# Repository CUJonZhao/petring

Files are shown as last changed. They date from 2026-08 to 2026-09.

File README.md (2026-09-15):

# Delta Rest & Activity Prototype

This repository contains the working files for Delta's rest/activity prototype,
including hardware, enclosure CAD, ESP32 firmware and experiment reports.

The current Stage 1B goal is to record IMU activity offline, review complete
sessions in a phone browser, and sync them automatically to a private website
after the board returns to home Wi-Fi. A harness-mounted walking monitor is being explored
because of the assembled enclosure's size; wearing/dog tests are deferred.

**Latest (2026-09-15):** The first Delta-worn outing reached the private website:
two adjacent sessions contain 7,604 valid samples across 6 min 26 s. The second
file passed the site's integrity check, though its unconfirmed end coincided with
a low 3.13 V reading. The site now uses conservative activity labels rather than
claiming dog walk/run recognition. See [today's report](docs/2026-09-15_daily_report.md).

**Resume here (2026-09-15):** [Today's report / 今日报告](docs/2026-09-15_daily_report.md) ·
[long battery recording](experiments/battery_recorded_long_2026-09-13.md) ·
[Home Wi-Fi auto sync / 回家自动同步](docs/2026-09-11_home_wifi_cloud_sync.md).
The board records by itself away from home Wi-Fi, closes the session after it reconnects,
uploads it to the private site, and keeps the newest segments when storage is full:
it deletes cloud-confirmed history first, then only the oldest local-only segment
if that is needed for recording to continue.
**Validated on the board (2026-09-11):** the loop now runs unattended. A session
started from movement alone while still on home Wi-Fi, ended itself after five minutes
of stillness, uploaded, and appeared on the private site: 6,724 samples at 19.53 Hz.
Rest/walk is calibrated from a labelled indoor recording (149/149 windows agreed); the
run boundary is not. Open: a short real walk and wearing it on Delta's harness.

Previous (2026-09-09): [Today's report, photos and next steps / 今日报告](docs/2026-09-09_daily_report.md).
[Firmware handoff / 软件交接](docs/2026-09-09_offline_motion_logging.md).
The user has reported v0.4 printing and assembly complete. The offline recorder
has now been backed up/upgraded and tested on the board: a two-minute USB run
saved 2,279 samples through a Wi-Fi-off interval; CSV/binary comparison and
restart persistence passed. See the [physical report](experiments/offline_usb_bench_2026-09-09.md).
Average sampling was 18.97 Hz with flash-write timing gaps. The one-hour
battery supply and recorded-battery tests have passed; wearing/dog testing
remains pending.
Earlier mechanical details: [Stage 1B handoff](docs/2026-09-09_stage1b_handoff.md).

- [Current print package](hardware/enclosure/print_packages/delta_collar_v0_4_fit_print_20260909.zip)
- [Base/lid instructions](hardware/enclosure/v0_4/README.md)
- [Placement and cable-routing image](hardware/enclosure/v0_4/placement_routing.png)
- [Assembled prototype photo](hardware/reference_images/stage1b_v0_4_assembled_2026-09-09.jpg)

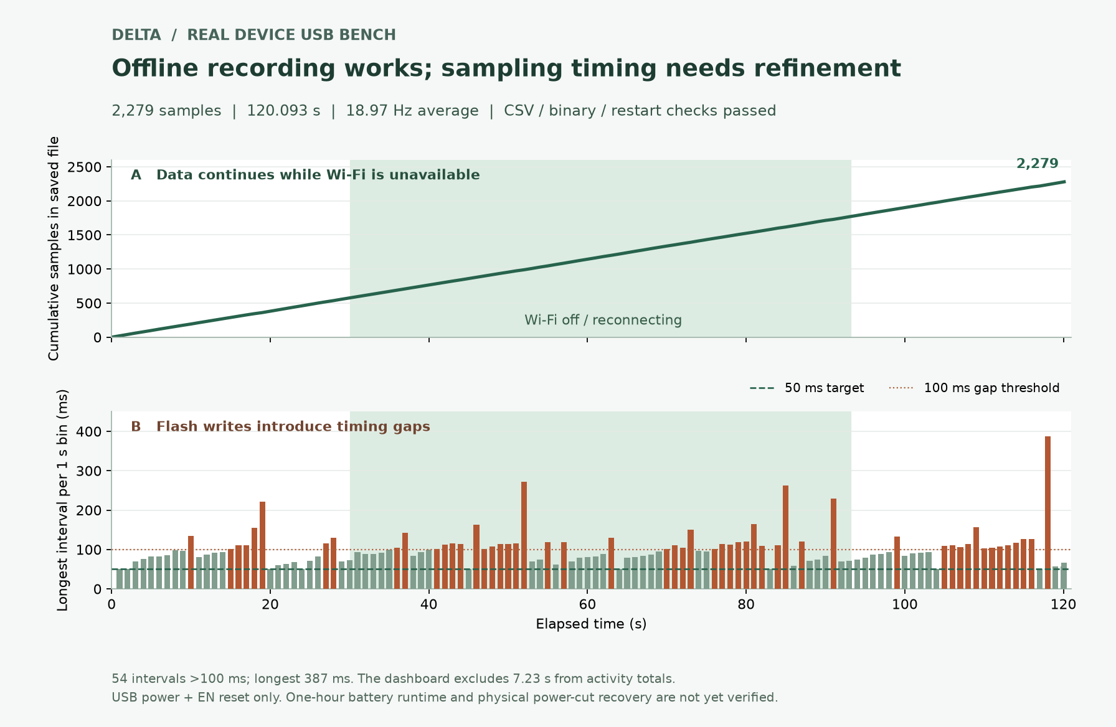
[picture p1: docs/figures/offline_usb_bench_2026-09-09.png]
Real USB bench: offline recording and sampling intervals


## Current Stage

Current status: Stage 1B home Wi-Fi auto-sync is implemented and passed a physical
bench end to end (record away, auto-close at home, upload, site confirmation).
The one-hour battery supply and recorded-battery validations have passed. A
real walk remains pending.

Stage 1A hardware bring-up is complete. The ESP32 Feather/HUZZAH32 V2,
LSM6DSOX IMU, LiPo battery path, Wi-Fi dashboard, enclosed USB bench test,
enclosed battery-only bench test, and four-minute hand-motion calibration have
all passed. The first dog-worn test is intentionally deferred because the
current enclosure is larger than desired for Delta.

Stage 1B focuses on:

- Reviewing the long battery recording's sampling gaps and capacity limit.
- Full-resolution data capture and automatic summary plots.
- Activity/rest threshold review from repeatable bench and hand-motion tests.
- Documenting the completed v0.4 enclosure and its remaining fit/retention details.
- Exploring a harness mount after the user resumes wearing tests.

As of 2026-09-06, a 3D printer has arrived and enclosure CAD work has
started. See
`docs/2026-09-06_stage1b_printer_arrival_and_enclosure_kickoff.md` and the
starting model in `hardware/enclosure/delta_collar_enclosure_v1.scad`.

As of 2026-09-08, the calipers have arrived and GitHub changes through
`7b54d0d` have been synced locally. Measured dimensions now feed a v0.3 low-wall
tray for powerless fit checks; see `hardware/enclosure/README.md`.
The first Feather, detached IMU, battery, and mounting-hole measurements are
recorded in `docs/2026-09-08_stage1b_caliper_measurements.md`. Hole-edge references
and the USB-inclusive length are confirmed, and mounting coordinates are derived.
Switch dimensions are recorded; the current preference is to mount it externally,
reserving cable exits and strain relief rather than internal switch space.
Underside and IMU slide-fit photos are archived. The user clarified that
19.59 mm measures the metal-pin gap, excluding the inward-projecting plastic
header bodies; the earlier usable-width estimate is withdrawn. The IMU can be
slid in from the side. The user confirms firm mechanical retention with no glue
or insulating layer, and an unchanged assembled height of 16.36 mm. Electrical
isolation and retention under motion remain to be verified; right-hand mounting
access was subsequently confirmed by the user on September 9.
A two-minute USB serial observation of this assembly then captured 2,370 samples
at 19.98 Hz with no firmware errors or post-startup resets. IMU temperature ranged
from 29.08 to 31.45 C. The user confirmed the battery was disconnected and reported
no physical anomalies during capture. See
`experiments/usb_slide_fit_2min_2026-09-08.md`; this is a short functional check,
not completion of enclosure, insulation, or wearability validation.

As of 2026-09-09, the user has printed the v0.3 tray and confirmed that the
board assembly and battery fit side by side with spare space. A removable
two-post cable guide (20 x 27 x 9 mm, shortened after the user's space check)
was designed for the long leads; see
`docs/2026-09-09_stage1b_tray_fit_and_cable_routing.md`. A v0.4 base and separate
lid now include four support posts, USB access, and a lay-in switch-wire exit.
The actual plug housing is 8.95 x 3.30 mm; the combined wire envelope is
3.32 x 1.59 mm, and the user confirms the IMU leaves the right holes accessible.
The battery plug's hard plastic projects 1.06 mm beyond the PCB edge, leaving
about 0.94 mm of nominal wall clearance; its raised wire bend needs a lid fit check.
See `hardware/enclosure/v0_4/README.md` for both STLs and fit instructions.
Mesh and nominal collision checks pass. The user subsequently confirmed printing
and assembly complete, with a [closed-case photo](hardware/reference_images/stage1b_v0_4_assembled_2026-09-09.jpg).
The final screw specification and internal retention details were not separately
confirmed; assembly completion does not certify wearing fit or waterproofing.

Stage 1 intentionally does not include medical diagnosis, production waterproofing, phone app deployment, GPS/LTE, or validated heart/respiration measurement.

## Next Work

Recommended next steps:

1. Take one supervised short real walk end to end: begin on battery, leave home
   Wi-Fi, return, and confirm automatic close and upload on the private site.
2. Review/download the real short recording in the phone-friendly `/records` page.
3. If fixed-rate behavior analysis is required, decouple sampling from synchronous
   flash writes and recheck interval distribution.
4. Use real recordings to refine activity reports. Do not advance wearing/dog
   testing until the user resumes that work.

## Repository Layout

- `docs/` - proposals, purchase/build notes, and PDF generation script.
- `firmware/` - ESP32 firmware (`imu_raw_stream` is the current recorder with home Wi-Fi sync).
- `hardware/` - wiring notes, enclosure sketches, hardware photos/diagrams, and enclosure CAD (OpenSCAD) starting point in `hardware/enclosure/`.
- `experiments/` - experiment plans and observation logs.
- `data/raw/` - raw CSV/log captures, ignored by Git except `.gitkeep`.
- `data/processed/` - processed analysis outputs, ignored by Git except `.gitkeep`.

## Key Documents

- `docs/canine_resting_vitals_smart_collar_proposal_v3_delta_first.md`
- `docs/canine_resting_vitals_smart_collar_proposal_v3_delta_first.pdf`
- `docs/stage1_purchase_and_build_notes.md`
- `docs/2026-08-12_stage1_handoff.md`
- `docs/2026-08-14_stage1_enclosure_bench_and_calibration.md`
- `docs/2026-09-06_stage1b_printer_arrival_and_enclosure_kickoff.md`
- `docs/2026-09-08_stage1b_caliper_measurements.md`
- `docs/2026-09-09_stage1b_tray_fit_and_cable_routing.md`
- `docs/2026-09-09_stage1b_handoff.md`
- [2026-09-11 daily report](docs/2026-09-11_daily_report.md)
- [2026-09-13 daily report](docs/2026-09-13_daily_report.md)
- [Home Wi-Fi auto sync](docs/2026-09-11_home_wifi_cloud_sync.md)
- [2026-09-09 daily report](docs/2026-09-09_daily_report.md)
- [Offline recording handoff](docs/2026-09-09_offline_motion_logging.md)
- [Physical offline USB bench](experiments/offline_usb_bench_2026-09-09.md)
- `experiments/usb_slide_fit_2min_2026-09-08.md`
- `hardware/enclosure/README.md`

## Safety Note

This is an engineering prototype, not a veterinary diagnostic device. During early tests, Delta should be supervised, the battery should not be compressed or exposed, and charging should not be left unattended.

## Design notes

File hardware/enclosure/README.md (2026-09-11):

# 小外壳：v0.4 底盒和盖子，沿用 v0.3 理线座

项目续接入口：[9 月 9 日日终报告](../../docs/2026-09-09_daily_report.md)。用户已确认 v0.4 打印和组装完成；当前优先离线记录，暂缓佩戴测试。

2026-09-09 最新：已根据补测完成 [v0.4 带盖试装版](v0_4/README.md)，包含 USB 开口、外置开关线槽与四根 Feather 支撑柱。

- [底盒 STL](v0_4/delta_collar_v0_4_base.stl)：65.25 × 65.25 × 21.36 mm，四柱已经合并在底盒内。
- [盖子 STL](v0_4/delta_collar_v0_4_lid.stl)：69.05 × 69.05 × 15.57 mm，包含向内伸出的线槽挡片，文件已摆成打印朝向。
- 两份都要导入；装配后名义总高 22.96 mm。网格、尺寸及名义碰撞检查通过；用户已完成打印和组装。
- 用户确认 IMU 不遮挡右侧孔；插头金属外壳为 8.95 × 3.30 mm，开关线合计外包络 3.32 × 1.59 mm。
- 柱子带 M2 试配导孔，实际锁固仍需螺钉。盖子松紧与全部线材走向需断电试装。

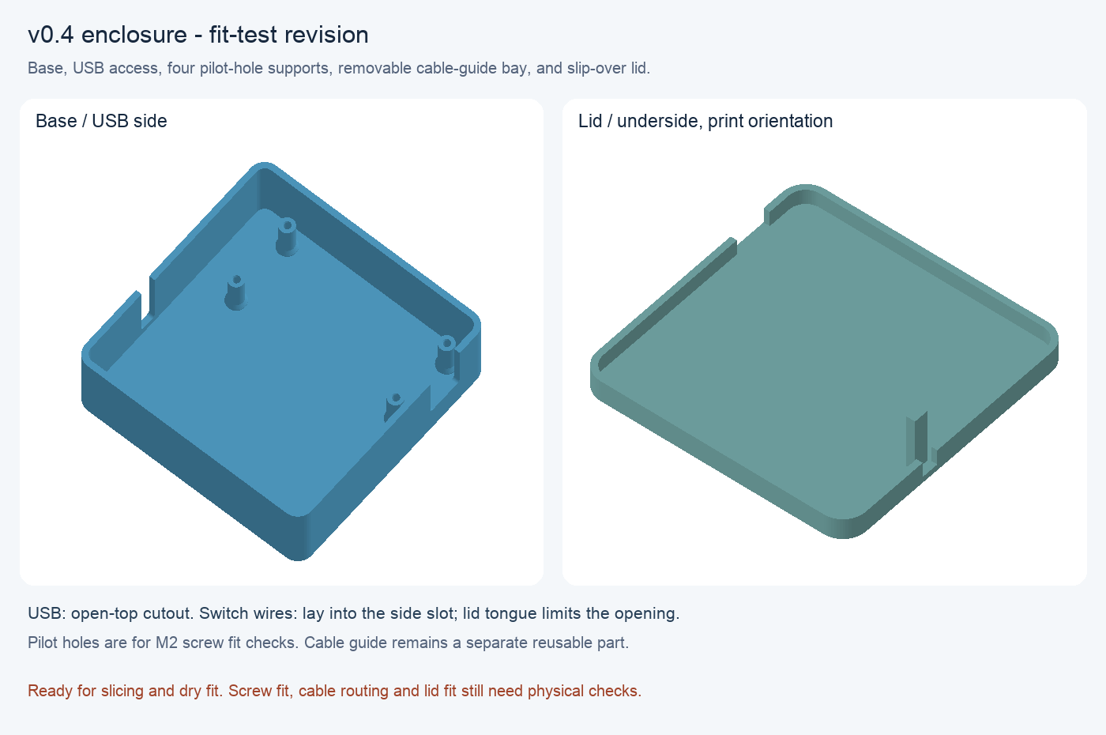
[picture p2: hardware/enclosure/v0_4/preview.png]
底盒及独立盖子


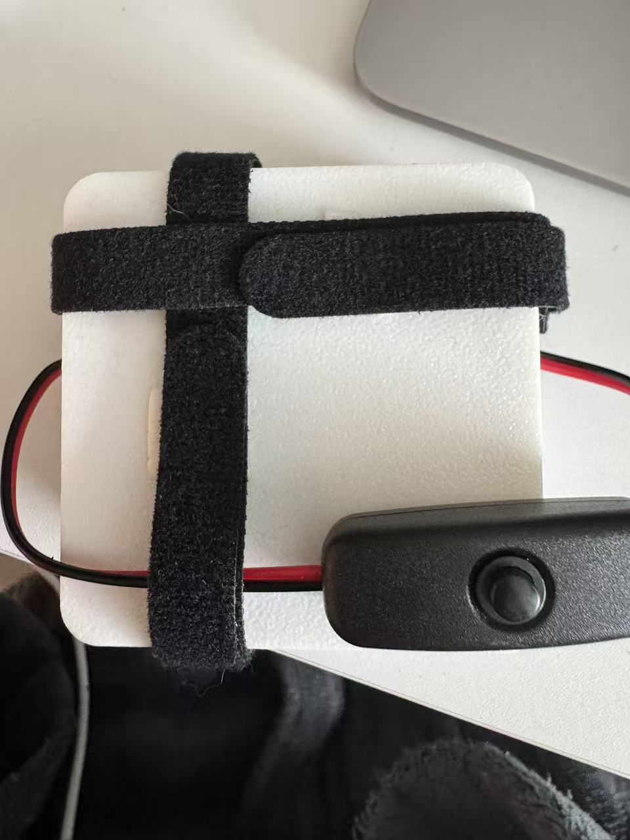
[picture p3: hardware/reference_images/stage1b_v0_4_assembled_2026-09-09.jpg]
已组装的 v0.4，交叉魔术贴和外置开关


照片记录整体外观；实际螺钉规格、内部固定和佩戴保持力仍没有单独验证。

## 正在试用的 27 mm 理线座

2026-09-09：用户已打印托盘并确认组件和电池可以并排放下，仍有空余空间；新增需求是整理较长的线材。

当前追加文件：[delta_collar_v0_3_cable_guide_27mm.stl](delta_collar_v0_3_cable_guide_27mm.stl)，尺寸 **20 × 27 × 9 mm**。
用户实测可用长边约 30 mm，已按要求缩至 27 mm；原 32 mm 版本仅作历史记录。
这是独立双柱理线座，可先放入电池旁空位试绕线，再用已有双面胶固定在托盘底面。
完整操作和摆放图见 [9 月 9 日理线记录](../../docs/2026-09-09_stage1b_tray_fit_and_cable_routing.md)。

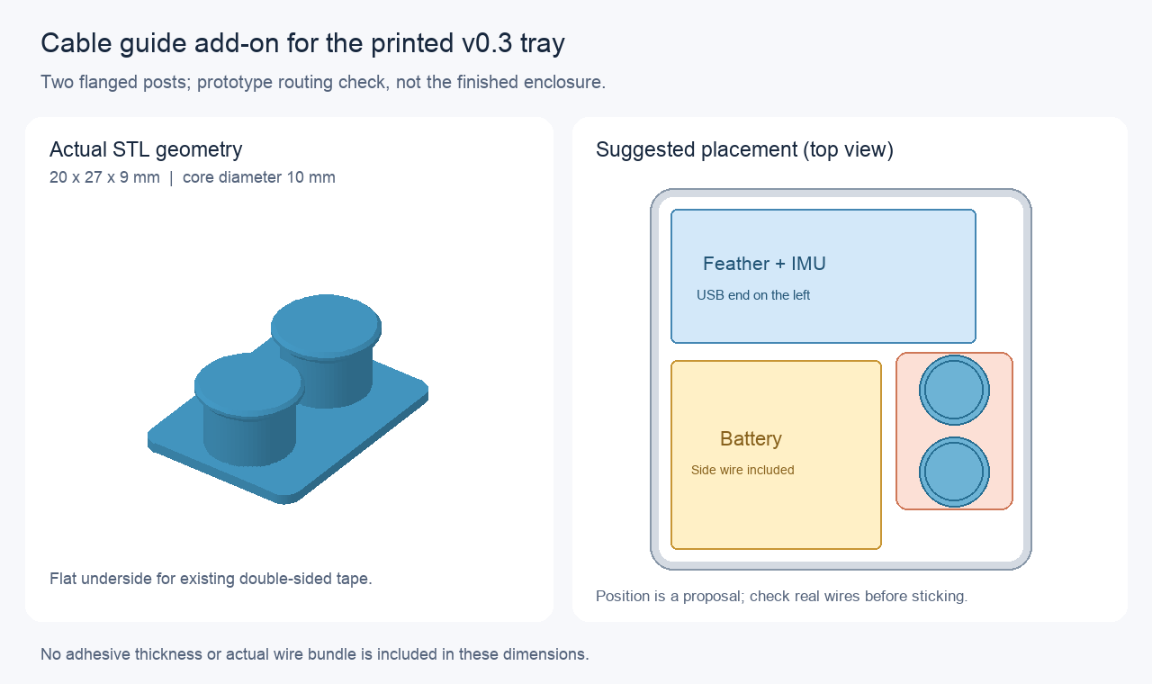
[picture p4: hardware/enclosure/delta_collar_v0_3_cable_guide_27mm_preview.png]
双柱理线座及建议位置


理线座已检查导出网格和尺寸。用户已确认整体组装完成，但合盖照片没有单独展示内部理线座及其固定效果。其 SCAD 可编辑；生成脚本依赖的库版本记录在对应 validation.json 中。
v0.4 给此配件预留位置，继续用独立理线座，便于复用和调整。

## v0.3 托盘参考

已打印的托盘文件：[delta_collar_enclosure_v0_3_fit_tray.stl](delta_collar_enclosure_v0_3_fit_tray.stl)。
此托盘用于断电检查占地和走线。它只有低侧壁，组件会高于侧壁；不是最终带盖外壳。

## 本版尺寸

| 项目 | 尺寸／状态 |
|---|---|
| 外尺寸 | 65.25 × 65.25 × 11.60 mm |
| 内部平面尺寸 | 62.05 × 62.05 mm（圆角附近空间略减） |
| 内部侧壁高度 | 10.00 mm |
| 底厚／壁厚 | 1.60／1.60 mm |
| Feather＋IMU 高度基准 | 16.36 mm；IMU 嵌在排针间，不重复加高 |
| Feather 含 USB 的参考占地 | 52.05 × 22.80 mm；外接线材另留空间 |
| 电池参考占地 | 35.90 × 32.25 mm，包含沿边电线 |
| 两组件摆放间距 | 3.00 mm，设计初值 |
| 周边留量 | 2.00 mm，设计初值 |
| 板长方向一端线材预留 | 8.00 mm，设计初值，不是已测弯曲半径 |
| 开关 | 外置 |

本版不设置固定柱，便于检查当前 IMU 位置是否挡住 Feather 右侧孔区。
四孔坐标已记录，但柱体直径和支撑通道尚未确定。低侧壁也让未确定出口位置的电线能够从上方绕出。

## 托盘原始试装步骤（并排占地已确认）

1. 拔掉 USB，保持电池与电路断开，保留当前卡住的 Feather＋IMU 组合，不为试装强拆。
2. 在 Bambu Studio 新建项目，导入上面的 STL。单位按 mm、缩放保持 100%，核对外尺寸为 65.25 × 65.25 × 11.60 mm。平底朝打印板、开口朝上，沿用已验证的打印机／材料配置。托盘几何不需要支撑；先切片检查有完整底面和开放顶部，再自行开始打印。
3. 冷却并清理毛刺后，轻放组件。Feather 的长边与托盘一边平行，电池放在它旁边，电池 35.90 mm 长边与 Feather 长边同向。开关留在盒外；不要叠压电池或用力把组件压向底面。
4. 检查：电池能平放取出；两组件和线材互不挤压；接头能插拔；四个 Feather 孔周围是否有放支撑柱的空间。元件高出低侧壁是预期效果，现阶段不尝试合盖或通电。
5. 把组合、电池和线材摆好，提供一张俯视照片和一张侧面照片，并指出碰到侧壁或走线太紧的位置。下一版据此确定柱位、完整盒高、出线口和盖子。

若目前已有打印好的旧托盘，可以先做同样的断电摆放，反馈卡住的位置；旧模型的电池宽度为 29 mm，与实测 32.25 mm 不符，不能据其尺寸认定新布局能放下。

## 文件与核对

- [SCAD 模型](delta_collar_enclosure_v0_3_fit_tray.scad)：含预览用组件包络，包络不导出到 STL。
- [生成脚本](generate_v0_3_fit_tray.py)：仅依赖 Python 标准库，修改脚本中的实测尺寸／设计留量并运行，可同步再生成 SCAD 和 STL。
- [网格检查结果](delta_collar_enclosure_v0_3_fit_tray_validation.json)：读取导出的二进制 STL 检查了外尺寸、544 个三角面、单个连通实体、每边恰好两个相邻面、朝向及体积。实体表面闭合，托盘顶部仍是开口；两者不是同一概念。

托盘导出时未运行 OpenSCAD 渲染或 Bambu 切片检查，也未由助手发起打印；用户后续已完成打印及并排摆放。导出使用与 SCAD 一致的轮廓直接生成网格。
旧 `delta_collar_enclosure_v1.scad` 及 v0.1／v1／v1_1 STL 保留为历史起点；当前带盖试装使用 v0.4 底盒和盖子，理线座使用带 `27mm` 后缀的 v0.3 文件。

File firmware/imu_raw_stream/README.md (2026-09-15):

# IMU stream and offline activity recorder

**2026-09-11 — home Wi-Fi sync.** Once site credentials are provisioned over USB
(`experiments/cloud_sync_mac.sh validate`), recording is automatic: a session starts
~10 s after the saved home Wi-Fi is out of reach (30 s grace after power-on), ends 15 s
after a stable home reconnect, and every unconfirmed session is uploaded newest-first
in resumable 16 KiB chunks with SHA-256 confirmation. When space is needed,
cloud-confirmed sessions are deleted oldest-first. If Delta remains away long enough
that this is not sufficient, it closes the current file, starts a new segment, and
evicts the oldest local-only segment only as needed to keep the newest data recording.
`GET /api/cloud` and serial `Q` report sync state; `/records` shows it with per-session badges. Without
credentials the original record-from-power-on behavior below is unchanged. Details:
[docs/2026-09-11_home_wifi_cloud_sync.md](../../docs/2026-09-11_home_wifi_cloud_sync.md).

**2026-09-09:** offline logging and the phone-friendly `/records` page are now
uploaded to the board. The first USB bench passed actual Wi-Fi-off recording,
CSV/binary comparison and restart persistence: 2,279 samples over 120.093 seconds,
18.97 Hz average. Synchronous flash writes caused 54 intervals over 100 ms;
timestamps preserve these gaps. One-hour battery runtime, direct power-cut
recovery and on-device full-disk behavior remain untested. See the
[physical bench report](../../experiments/offline_usb_bench_2026-09-09.md).

This Stage 1 test firmware configures the LSM6DSOX for a 104 Hz accelerometer (+/-4 g) and gyroscope (+/-500 deg/s) sample rate. It sends a CSV row to USB serial every 50 ms and samples the Feather's battery-voltage divider once per second.

It also runs a password-protected Wi-Fi access point:

- Network: `Delta-Collar`
- Password: `deltacollar`
- Dashboard: `http://192.168.4.1`

Connect a phone or computer to the `Delta-Collar` network, then open the dashboard
address in a browser. The dashboard shows live sensor data, a simple Resting/Active
state, battery voltage, a short activity chart, and browser-side CSV export.
The live chart/export still covers only about 45 seconds; use **离线记录 / 完整历史**
(`/records`) for recordings saved on the device. Neither page needs internet.

## Offline recording workflow

1. Power on. If the IMU and storage initialize successfully, a **new recording
   starts automatically**, even without a phone, router or internet connection.
2. In `/records`, check that the saved sample count increases. Closing the page
   or leaving home Wi-Fi does not stop recording.
3. Reconnect directly to `Delta-Collar`, or visit the device's local IP on home
   Wi-Fi. Press **停止并保存** before switching power off or downloading data.
4. View an entire recording, download CSV, or download the original binary file.
   The CSV has every validated saved sample, not just the browser chart window.
   Confirm the download in the phone's Files/downloads before deleting anything.
5. Press **开始新记录** to record again without rebooting. This attaches the phone's
   current date/time to the new session. Automatic boot/serial starts have relative
   time only, explicitly shown as `未设置日历时间`; no offline clock is invented.

The recorder targets 20 samples/second and preserves raw accelerometer/gyroscope
counts, sensor temperature, battery voltage, a quantized activity score and the
heuristic state. Data is buffered for at most about one second during normal
operation and flushed using checked `fflush`/`fsync`; a normal stop flushes the
remaining partial batch. Each record has a CRC. Unexpected power loss can lose
the pending batch/in-flight write; the actual power-loss behavior needs a board
test. This is not a hard real-time or lossless acquisition guarantee: flash and
network servicing may add timing gaps. The recorded timestamps preserve them.

An unclosed `.open` file is retained as **interrupted** after reboot; a new file
is created without resuming or overwriting it. Normal stops use `.bin`; full disk,
write errors and repeated IMU failures use `.full`, `.error`, `.sensor`.
Twenty consecutive IMU read failures stop recording. With home sync configured,
storage acts as a latest-record ring: cloud-confirmed history is discarded first;
if that cannot make room during a long away recording, the oldest local-only
segment is discarded and the newest segment continues. This means an exceptionally
long trip with no return to home Wi-Fi can lose its oldest not-yet-uploaded segments.
The current segment is never deleted while it is being written. Without home sync
credentials, full storage still stops capture and is reported in the UI.

Large transfers, directory listings and deletions are rejected with HTTP 409
while recording, so a CSV download cannot pause an active session. Small status
and live dashboard requests remain available. Wi-Fi remains enabled for access
and reconnection by default. Serial `O` temporarily disables Wi-Fi without stopping
the recording; `W` restores Wi-Fi and the saved network; `N` prints network status.
These controls allow a bench test with the radio actually disabled. They do not
erase credentials and are not persistent across reboot. Home Wi-Fi cloud upload is
described at the top of this file; Bluetooth sync and a phone-page radio control
are not implemented.

## Storage and migration

`partitions.csv` preserves the offsets and sizes of **all existing partitions**,
including NVS/Wi-Fi credentials and the old `spiffs` battery-log partition. The
formerly unused upper 4 MiB at `0x400000` becomes a separate `motion` LittleFS
filesystem. This partition layout is for the **8 MB Feather ESP32 V2 only**.
The build pins Espressif32 7.0.1 / Arduino 2.0.17, whose LittleFS configuration
supports three partitions; this firmware mounts two.

- New record payload: 24 bytes/sample, 32-byte session header.
- One hour at 20 Hz: **1,728,032 bytes** (~1.73 MB / 1.65 MiB), before filesystem overhead.
- A 128 KiB reserve is maintained; displayed remaining time also allows 15% for
  overhead. It estimates storage capacity, **not battery life**.
- The observed practical ceiling is about **150,000 samples / 130 minutes** in
  one continuous segment (the 2026-09-12/13 battery recording). With ring
  retention enabled, longer away periods are split into segments and retain the
  newest ones instead of stopping at that boundary.
- Existing battery logs remain in their original partition.
- Mounting never uses destructive format-on-failure. A partition is initialized
  only after a full scan proves that every byte is erased (`0xff`). An unreadable
  nonempty partition is left intact, reported unavailable, and requires recovery.
- Use a normal firmware upload, which includes the new partition table. **Do not
  use `erase_flash` or `uploadfs` for this upgrade.** Back up the board's existing
  data before an upgrade. The first physical upgrade has been backed up and
  performed; all 560 pre-existing battery rows were preserved.

## Saved format and recovery

All numbers use explicit little endian encoding in `src/motion_format.h`.
Header: `DLOG`, uint16 version 1, uint16 record size 24, uint32 period 50 ms,
uint32 start uptime, uint64 optional start Unix milliseconds (0 = unknown), six
reserved bytes, CRC-16/CCITT-FALSE over the first 30 bytes.

Record: uint32 elapsed ms; three int16 acceleration counts; three int16 gyro
counts; int16 temperature count; uint16 battery mV; uint8 rounded activity score
times 255; uint8 flags (bit 0 Active); CRC-16/CCITT-FALSE over the first 22 bytes.
CRC parameters: polynomial 0x1021, init 0xffff, no reflection/final xor.
Acceleration scale is 0.000122 g/LSB, gyro 0.0175 deg/s/LSB, temperature
`25 + count/256` C. It is IMU chip temperature, not animal body temperature.

The device validates all full records before CSV export. The page also compares
the received CSV row count with `X-Delta-Records` before reporting success, and a
read failure during streaming aborts the transfer. An incomplete final
record is omitted (and its byte count shown); corrupt full records cause HTTP
422 instead of silently exporting bad measurements. Download the original binary
for independent inspection/recovery:

```sh
python3 experiments/decode_motion_log.py data/raw/delta-ID.bin data/processed/delta-ID.csv
# Only if corruption was reported: explicitly recover the intact prefix.
python3 experiments/decode_motion_log.py data/raw/delta-ID.bin data/processed/delta-ID.csv --recover-prefix
```

Run those commands from the repository root. The decoder reports record count,
last timestamp, optional start time and any recovery warnings as JSON. It writes
the CSV atomically, preserving an existing output if validation fails. CRC damage
ends recovery at the first bad record; it does not guess missing values.

Saved CSV columns:

`elapsed_ms,ax_g,ay_g,az_g,gx_dps,gy_dps,gz_dps,temp_c,motion_g,activity_score,battery_v,state`

The history page reads the full CSV and plots time-binned averages. Activity/low
activity durations use successive valid intervals <=100 ms; larger gaps and the
time before the first sample are marked uncovered. This is an exploratory
threshold summary, not a validated behavior classifier.

## Tests

```sh
# From the repository root; Python 3 + a C++11 compiler.
python3 firmware/imu_raw_stream/tests/test_offline_log.py
# With Playwright available to Node:
node firmware/imu_raw_stream/tests/records_page_test.cjs
# From this firmware directory:
pio run
```

The host test exercises the actual C++ buffer/codec with 72,000 synthetic samples,
an independent Python CSV decoder, bit corruption, every possible truncated tail,
timestamp regression, failed writes/partial buffers, and partition compatibility.
The browser test uses mocked device APIs, checks full-hour chart/download, state
controls, interrupted sessions, errors, disconnect/reconnect, deletion cancellation
and mobile overflow. These do not substitute for LittleFS/power-loss/battery tests
on the ESP32. Set `PLAYWRIGHT_CHROMIUM_EXECUTABLE` to use an installed Chrome and
`DELTA_UI_TEST_OUTPUT` to choose the screenshot/download output directory.

For an attached board with this firmware already uploaded, the physical USB
bench script records 120 seconds, temporarily disables the board's Wi-Fi for
about 60 seconds, downloads and compares CSV/binary data, and uses an EN reset to
check completed/interrupted records. It creates sessions but never deletes them:

```sh
python3 experiments/validate_offline_recorder.py --port /dev/cu.usbserial-59680111041 \
  --url http://DEVICE_IP --output data/raw/offline_bench_RUN
```

Run from the repository root with `requests` and `pyserial` installed. The script
restores Wi-Fi and stops recording on exit. An EN reset is not a physical power
cut and this USB-powered run does not measure battery endurance.

To also use the dashboard while the computer stays on home Wi-Fi, open `http://192.168.4.1/setup` while connected to `Delta-Collar`. Enter the home network name and password in that page. After the ESP32 connects, the page displays its new local IP address and stops the temporary access point to reduce normal operating power. If the home network becomes unavailable, `Delta-Collar` automatically returns for configuration or recovery.

The existing USB serial CSV columns remain:

`ms,ax_g,ay_g,az_g,gx_dps,gy_dps,gz_dps,temp_c,motion_g,battery_v`

With the board still on a desk, the acceleration magnitude (`motion_g`) should stay near `1.0`. During tilting or hand motion, the axis values and gyroscope values should change.

## Run

1. Keep the LSM6DSOX connected to the Feather STEMMA QT port.
2. From this directory, run `pio run --target upload`.
3. Open serial at 115200 baud and collect the CSV output.

`battery_v` is an approximate voltage from the onboard 1:2 voltage divider. It is useful for tracking charge and discharge, but it is not a calibrated battery gauge.

Every 30 seconds, the firmware also saves `ms,battery_v` to its original internal
flash partition. Serial commands: `S` stops/saves motion recording; `R` starts a
new recording; `L` prints recording status; `D` prints the old battery log (only
when motion recording is stopped); `C` clears only the battery log. None of these
commands delete motion sessions. Stop before unplugging USB to end a session cleanly.

The IMU configuration is not persistent: it resets when the board loses power.

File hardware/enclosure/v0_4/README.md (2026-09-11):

# v0.4：带 USB 开口、出线槽、四柱和独立盖子的试装版

2026-09-09。沿用已经通过实物并排试放的底盒平面尺寸，增加完整高度、Feather 支撑柱和盖子。
用户现已确认打印、组装完成，照片可见魔术贴保持盖子与外置开关；见 [今日报告](../../../docs/2026-09-09_daily_report.md)。
下文保留参数、打印与复装参考。具体螺钉规格、内部保持力及佩戴配合没有被这张合盖照片单独验证。

底盒与盖子，均为打印方向

## 打印文件

可直接下载 [v0.4 试装打印包](../print_packages/delta_collar_v0_4_fit_print_20260909.zip)：包含下列两份 STL、可选的 27 mm 理线座、摆放图和简明说明。打包时已核对 STL 尺寸与压缩包内文件哈希。

| 零件 | 文件 | 导入后尺寸 X × Y × Z（mm） | 朝向 |
|---|---|---|---|
| 底盒，含四根柱子 | [delta_collar_v0_4_base.stl](delta_collar_v0_4_base.stl) | 65.25 × 65.25 × 21.36 | 平底贴板、开口向上 |
| 盖子，含出线挡片 | [delta_collar_v0_4_lid.stl](delta_collar_v0_4_lid.stl) | 69.05 × 69.05 × 15.57 | 外侧大平面贴板，盖内侧及挡片向上；文件已翻好 |

两份都要导入，作为两个独立物体排列，缩放保持 100%。不要把盖子重新翻成盖住底盒的方向打印。
盖子主体只有 5.6 mm 高，STL 的 15.57 mm 高度包括向盒内伸出的出线挡片。装好后的总外尺寸为 **69.05 × 69.05 × 22.96 mm**。

沿用已验证的打印机、材料和参数。按给定方向，几何没有要求额外支撑的封闭悬空顶面；仍先检查切片预览，确认四根柱子、柱内导孔和盖上挡片完整。助手未启动打印。

## 本次收到的补测

- 实际 USB 线插头外壳：**8.95 × 3.30 mm**。用户澄清外壳为金属，原先关于“塑料头高度一致”的描述不作为另一个尺寸。
- 当前 IMU 不遮挡 Feather 右侧两个孔，用户确认下方可放支撑柱。
- 白色电池插头插好后，硬塑料超出 Feather PCB 长边 **1.06 mm**，不含软线。当前位置板边至内壁 2.00 mm，因此硬插头名义平面间隙约 **0.94 mm**；此数值不能作为软线弯曲空间。
- 开关线合并的自然外包络：**3.32 × 1.59 mm**，按本次询问的合计宽、厚记录。槽内需容纳的全部线应一起试放。
- 组合高度继续采用 **16.36 mm**，不再次叠加 IMU 厚度，也不要求拆出 IMU 加胶。

## 结构和装配

**Feather 四柱。** 柱顶距盒内底面 10.10 mm，对应 9.10 mm 下排针突出量加 1.00 mm 离底间隙。柱身直径 4.00 mm，底部加宽到 5.20 mm。四孔位置采用用户孔内缘测量所推导的坐标，仍需实物对孔。柱内为直径 1.60 mm、深 6.00 mm 的 M2 试配导孔，入口带扩口；柱子负责支撑，配合适的螺钉后才形成锁固。

现有采购记录没有确认 M2 螺钉。没有螺钉也能先轻放板组检查四孔和高度，不能把这一步当作板子已固定。螺钉长度取决于实际穿板厚度，伸入柱内应短于 6 mm；导孔是否适合所用螺钉还需试配，不是预制金属 M2 螺纹。

**USB 充电/数据开口。** 位于 Feather USB 一侧，净宽 **10.15 mm**，即插头宽度每侧加 0.60 mm。开口从距内底面 6.00 mm 处一直开到上缘，合盖后最高净空 13.36 mm；底角圆角处宽度略减。较大的垂直窗口用于容纳尚未直接测量的接口中心高度，实际插入时核对外壳及线根不碰盒壁。盖裙同步避让，合盖后可插拔 USB。接口沿板宽居中的位置参考 [Adafruit 官方 PCB 文件](https://github.com/adafruit/Adafruit-ESP32-Feather-V2-PCB)，板长、板宽与四孔位置继续以用户实测为准。

**外置开关出线口。** 位于理线座一侧的盒壁，槽宽 **4.52 mm**，底部圆角半径 1 mm。合盖后开口最大高度 **3.39 mm**，在圆角以上已核对 3.32 × 1.59 mm 的矩形线束可通过。开盖时直接把线放入 U 形槽，再盖上盖子，免去把既有插头穿过小孔。挡片厚 2.20 mm，进入槽内但不夹紧线束；它限位，不代替外部防拉扯固定。

**盖子。** 外套式盖裙，单侧设计间隙 0.30 mm、重叠高度 4.00 mm，顶厚 1.60 mm。当前是台架试装配合盖，没有锁扣；实际松紧取决于打印结果。使用现有魔术贴可作临时整盒保持，后续再结合外部开关及项圈固定一起验证。不要靠挤线来让盖子落到底。

**27 mm 理线座。** 继续使用 [20 × 27 × 9 mm 独立配件](../delta_collar_v0_3_cable_guide_27mm.stl)，本版留位，不重复打印或合并到盒底。相对底盒外角的建议左下/起始坐标仍为 X=42、Y=28 mm；电池起点为 X=3.6、Y=29.4 mm。坐标方向见下文装配预览：USB 在 X 最小的一侧，Feather 和电池沿 Y 并排。模型已检查理线座实体不碰挡片；粘胶厚度、绕线后的高度及余线回弹还需要实际试放。

## 复打／复装参考步骤

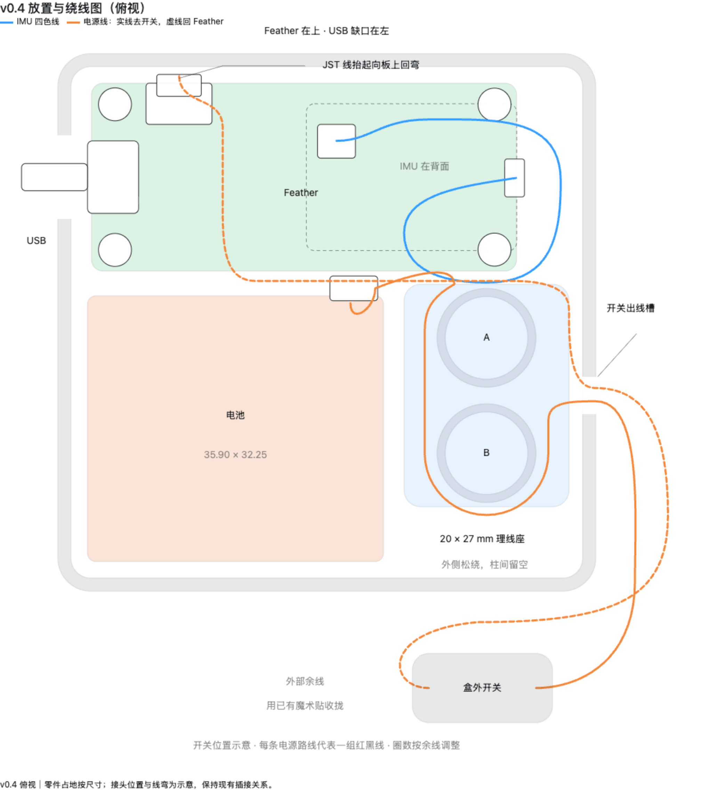
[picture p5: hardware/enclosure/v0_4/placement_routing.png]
建议俯视摆放与走线


可下载 [交互图 HTML](placement_routing.html) 后用浏览器打开，分别切换 IMU 线和开关电源线。[可编辑图源](placement_routing.fragment.html)已随仓库归档。图是本版参数的快照，修改 CAD 布局后应同步更新图中的尺寸与路线。

摆放图的零件占地来自本版参数；插接点、接头形状和软线走向为示意，不是按线长或最小弯曲半径完成的仿真。每条橙色路线代表一组红黑线：实线从电池经外侧绕柱到外置开关，虚线由开关回到 Feather；蓝色代表整条 IMU 四色线。保持现有插接关系，不改接线。

先只摆组件，再放 IMU 松弯，最后沿两柱外侧整理电源余线。IMU 线不强行绕完整一圈，也不穿过两柱挡边之间的窄缝。Feather 电池插头处的线向上抬起后回弯到板上方，不向 0.94 mm 的边缝塞线；这段和 IMU 松弯都需检查合盖高度。图中接头可在邻近可用空间微调，不能压在电池下或用盖子压住。

1. 等当前理线座完成，先试放和松绕线，记录是否有线圈超出底座占地。
2. 导入本版底盒和盖子，核对上表尺寸与朝向，再切片打印。
3. 断开 USB 和电池后，板组轻放到四柱上，检查每个孔都对准、板子平稳、排针不顶底；不要为对孔强拆 IMU。
4. 电池平放到旁边，理线座放入预留空位；把所有要通往开关的线一起放进槽内，开关保持外置。
5. USB 线电脑端断开时试插拔板端；再轻合盖，检查挡片没有夹线、盖沿能够落到底。反馈顶视图和侧视图及任何碰撞点，再调整间隙和完成固定。

用户已确认整体组装，后续也完成了 USB 离线记录短测。板组锁固、电池保持、外置开关及线材防拉扯的具体细节与佩戴保持力仍需单独记录；USB 短测不等同于完整机械或续航验证。

## 参数与检查

- [design_inputs.json](design_inputs.json)：实测值与设计留量分开记录。未知实测值为 null 时，正常导出会拒绝，`--draft` 仅输出带后缀的评审草稿。
- [generate_enclosure.py](generate_enclosure.py)：参数化实体生成、STL 重新读入验证和实际网格预览。Python 依赖见 [requirements.txt](../requirements.txt)，验证时使用 Python 3.12.3。绘图字体当前使用 macOS 系统 Arial，换系统时需修改字体路径。
- [assembly.scad](assembly.scad)：装配查看器，导入生成的 STL 和组件包络；`show_lid=true` 查看盖合位置。尺寸编辑入口是 JSON，不是这个查看器。
- [validation.json](validation.json)：底盒 4,028 面、盖子 602 面；各为单个闭合实体，朝向一致、无退化面、外尺寸正确。名义合盖状态无底盒/盖子体积干涉，USB 与线束通道探针通过，电池及理线座的名义包络无干涉。

生成命令：

```sh
python hardware/enclosure/v0_4/generate_enclosure.py
```

网格和名义包络检查不能替代实际打印公差、焊点/接插件占位、螺钉试配与最终线材布局检查。

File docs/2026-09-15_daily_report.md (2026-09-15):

# Delta 项目日报与续接指南 — 2026-09-15

今天完成了第一次 Delta 实际佩戴外出的数据核对，并把设备的满存策略改成
“优先保留最新记录”。网站的活动摘要也已改成更保守的观察标签，避免把尚未
用犬只真实数据标定的阈值误说成“走路／跑步识别”。

## 今天的结论

| 项目 | 状态 | 可复核结果 |
|---|---|---|
| 首次 Delta 佩戴外出 | **数据已收到** | 网站已有两段相邻记录：9 月 14 日 21:13:17（3 分 02 秒、3,586 条、正常结束）和 21:17:04（3 分 24 秒、4,018 条） |
| 第二段的文件完整性 | **通过** | 网站保存了完整原始文件；4,018 条有效样本，19.7 Hz，采样间隙 4.2 秒（跨度的 2.1%） |
| 第二段的结束原因 | 待结合现场确认 | 记录内电压 3.30 → 3.13 V，且没有写入正常结束标记；这与低电压／掉电相符，但不把它当作已由硬件完全证明的结论 |
| 充电复核 | 正在恢复 | 外置开关打开后，实测工作电压曾由约 3.87 V 上升至约 3.96 V；CHG 指示灯亮表示正在充电，不能单独证明已充满 |
| 私有网站 | 已更新并发布 | 活动呈现改为观察性“静止／活动／持续高活动”；低电压提示和相邻分段汇总已加入，站点仍仅所有者可见 |
| 本地固件的最新记录保留 | 代码和主机模拟通过 | 满存时先删除已被网站确认的最旧记录；仍不足才删除最旧的仅本地旧分段；当前写入的分段绝不删除 |
| 板子固件 | **已刷写并启动验证** | 以普通固件上传完成芯片端哈希校验；未执行 `erase_flash` 或 `uploadfs`，运动分区未被清空 |

## 外出数据：没有白费

两段记录合计 **6 分 26 秒、7,604 条样本**。两段之间约有 45 秒间隔，
因此不能视作严格连续的一条轨迹；但每一段实际到达网站的数据都有效。第一段
正常结束；第二段虽标为“结束待确认”，网站的完整性校验通过，表示原始文件
不是因传输而丢失或损坏。

第二段结束时的 3.13 V 已明显偏低，结合当时设备中途停止的现象，低电压是目前
最合理的解释。下一次外出前，应在外置开关**打开**的状态下继续充电至 CHG 熄灭
或电池工作电压稳定在约 4.1–4.2 V；充电仍须有人看护，若电池异常发热、鼓包或
有异味则停止使用。

## 容量与新的满存策略

`motion` 分区为 **4 MiB**；每个 IMU 样本为 24 字节，20 Hz 时理论上一小时
原始数据约为 1.73 MB。实际长记录已经测到单段 **150,289 条、130 分 38 秒**，
这比公式更可信地代表当前文件系统和采样间隔下的容量边界。

原来的行为是：已上传的记录可在空间紧张时清理，但如果设备长时间离开家中
Wi-Fi、所有旧记录都尚未上传，记录会最终因存储满而停止。现在的固件改为：

1. 空间需要时，先清理网站已以 SHA-256 确认收到的最旧文件；网站上的副本保留。
2. 若仍不足，当前段会先正常收尾，再新开一段；仅删除最旧的、尚未上传的
   本地旧段，给新段让出空间。
3. 正在写入的当前文件和刚结束、最新的那一段都受保护，长途记录会成为若干
   分段，设备尽可能保留最近的部分。

这是明确的数据取舍：**极长时间不回家同步时，最早的未上传分段可能会被淘汰，
以换取最新的记录继续保存。** 在能回家同步的正常流程中，优先删除的是已有
云端完整副本的历史记录。

实现位于 [cloud_sync.cpp](../firmware/imu_raw_stream/src/cloud_sync.cpp) 和
[cloud_sync.h](../firmware/imu_raw_stream/src/cloud_sync.h)；手动开始、自动离家开始
和家中活动开始均使用同一套空间策略。本地 `/records` 页会显示本次开机清理数，
并区分其中有多少是“仅本地旧段”。

## 网站分析的调整

私有网站已发布新的观察规则：

- 静止阈值：低于 **50 mg**；
- 高活动阈值：高于 **600 mg**；
- 只有连续 **6 秒**的高活动才显示“持续高活动”；短暂峰值只作为短时高活动候选；
- 不再把这些当前阈值直接命名为犬只“走路／跑步”。

这些是展示和后续校准的起点，不是医学指标，也不是已由 Delta 真实佩戴数据验证
的步态分类。下一次在充分充电后取得更长的佩戴样本，才能据此调整阈值。

## 验证和已知边界

- `sh firmware/imu_raw_stream/tests/cloud_sync_sim/run.sh`：通过。该主机模拟验证
  了“已确认记录优先”，以及仅在显式启用后才会移除最旧的未上传闭合分段；活动
  文件不会被删除。
- `python3 firmware/imu_raw_stream/tests/test_offline_log.py`：通过。它检验一小时的
  二进制编码、CRC、批量写入和部分批次收尾。
- `git diff --check`：通过，无空白错误。
- PlatformIO 目标板编译：通过（ESP32 Feather V2，RAM 15.2%、应用分区 85.1%）。
- 普通固件上传：通过；芯片端写入哈希校验完成并以 RTS 重启。上传只擦写引导、
  分区表、OTA 元数据与应用分区的必要区域，没有执行 `erase_flash` 或 `uploadfs`。
  重启后 LSM6DSOX 就绪、设备已连回家中 Wi-Fi，状态 JSON 已含
  `evicted_this_boot` 字段，证明新固件在运行。启动时电池工作电压约 **4.20 V**。

## 下次如何继续

1. “最新记录保留”已在 Delta 上生效。下次升级仍只使用普通固件上传；上传会
   重启设备，且不应使用擦除 flash 的流程。
2. 电池已读到约 4.20 V。拔 USB 后等待正常启动，再进行短时间、
   有人看护的佩戴测试。
3. 回到家中 Wi-Fi 后保持设备开机，等待自动结束和上传；在网站确认文件完整后
   再接 USB 充电。
4. 以多个真实佩戴片段复核“静止／活动／持续高活动”阈值；不要基于一次短测
   把它解释为可靠的跑步或健康诊断。

## 续接入口

- 本日报：[2026-09-15_daily_report.md](2026-09-15_daily_report.md)
- 长电池记录容量依据：[battery_recorded_long_2026-09-13.md](../experiments/battery_recorded_long_2026-09-13.md)
- 自动回家同步设计：[2026-09-11_home_wifi_cloud_sync.md](2026-09-11_home_wifi_cloud_sync.md)
- 设备固件说明：[firmware/imu_raw_stream/README.md](../firmware/imu_raw_stream/README.md)
- 私有网站：[Delta 散步记录](https://delta-walk-jz-20260911.yesmora.chatgpt.site/)

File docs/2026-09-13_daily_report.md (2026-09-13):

# Delta 项目日报与续接指南 — 2026-09-13

今天把 Stage 1B 最后一个电池记录缺口补齐：设备在电池供电下连续保存
**130 分 38 秒**，并自动把完整二进制记录上传到私有网站。原计划是一小时，
但设备实际运行得更久；这额外验证了容量边界、低电量下保存，以及上传后自动
释放设备空间。

## 现在已经完成什么

| 项目 | 状态 | 关键结果 |
|---|---|---|
| 一小时电池待机 | 通过 | 63 分 02 秒无重启，3.914 → 3.756 V；见 [待机实验](../experiments/battery_bench_1h_2026-09-12.md) |
| 一小时电池连续记录 | **通过** | 会话 `bfe0a2f2`：130 分 38 秒、150,289 条、19.174 Hz；见 [长记录实验](../experiments/battery_recorded_long_2026-09-13.md) |
| 长记录的保存与回家上传 | **通过** | 私有网站已收到 3,522.4 KiB 原始文件并完成完整性校验 |
| 网站 | 正常 | [Delta 散步记录](https://delta-walk-jz-20260911.yesmora.chatgpt.site/) 已上线、仅所有者可见；今天显示 23 段历史记录 |
| 设备本地状态 | 正常待机 | 未在录制、Wi-Fi 已连回家、云端待上传 0、可用空间约 4 MiB |
| GitHub | 已同步 | 本仓库 `main` 已推送；网站源码在独立私有仓库 `CUJonZhao/petring-site` |

长记录的网页数据：电池在记录内由 3.83 V 降至 3.59 V；采样间隙合计
6 分 19 秒（跨度的 4.84%）；静止分类为全程静止，活动指数 1.5 mg。记录
在约 130 分钟时结束，网页标为“非正常结束”。它结束和上传都早于 USB
重新接回；结合 3.52 MiB 文件大小和固件保留空间规则，最可能原因是达到
存储上限，而不是数据丢失或电池突然断电。

设备接回 USB 后最初读到 3.322 V，随后在约两分钟内升至 3.464 V；本次
连接确认充电恢复。日报整理时读数为 3.572 V，仍在充电。

## 今天新增的工具与文档

- [battery_recording_session.py](../experiments/battery_recording_session.py)：为受控的电池记录准备了 `status`、`start`、`stop` 三个操作。它会在停止后下载 CSV 与二进制文件，并核对记录数。
- 该工具的正确停止顺序已经写明：**回到家里 Wi-Fi 后，保持 USB 拔掉，先停止并保存；再接回 USB。** USB 接入会重启板子，不能作为正常结束记录的方式。
- [长记录实验报告](../experiments/battery_recorded_long_2026-09-13.md)：记录了全部可复核数字、结论与容量限制。
- 最近推送的提交：`707624d`（长记录结果）、`11de18a`（记录辅助工具）、`f2a696f`（一小时待机测试）。

## 充电的小观察

如果外置电源开关已经打开时插入 USB，CHG 灯曾不亮；保持 USB 接入、将外置
开关关一次再打开后，CHG 灯会亮，电压也确认开始回升。当前原型可以继续测试，
但充电时请保持盒子打开并有人看管；若 CHG 未亮，先做一次这个开关重连并确认
电压开始上升。暂不为此中断后续的软件／实地验证。

## 下次从这里继续

下一项是**短距离真实散步的自动闭环测试**。先让电池继续充电；当设备准备好，
按下面顺序即可：

1. 保持外置开关打开，拔掉 USB。设备会以电池重启；等约半分钟。
2. 用手安全带着设备走动约 30–40 秒，确保运动触发开始记录；随后进行一次短
   散步，建议 10–30 分钟，远低于约 130 分钟的单段容量上限。
3. 回到家后把设备保持开机、不要立刻插 USB。等待稳定连接与上传；我会检查
   网站的新记录、持续时间、采样间隙、电压和活动摘要。
4. 确认这段记录已正常结束、显示在网站后，再插 USB 充电。

这次先手持或固定在非犬只物品上完成闭环。狗佩戴仍应等胸背固定方案和实际
佩戴意愿明确后再开始。真实记录回来后，再用它校准狗佩戴位置下的静止／走路／
跑动阈值；当前 50 mg 的走路阈值只在室内手持标定中验证过。

## 开工速查

| 想做的事 | 入口／做法 |
|---|---|
| 看网站历史 | [网站首页](https://delta-walk-jz-20260911.yesmora.chatgpt.site/)；最新长记录是 9 月 12 日 21:57 的 130 分 38 秒记录 |
| 看设备是否充电、在线 | `curl http://172.24.23.133/api/latest`；电压只作趋势参考，不是精确电量百分比 |
| 看记录与上传状态 | `curl http://172.24.23.133/api/recording` 与 `curl http://172.24.23.133/api/cloud` |
| 受控电池记录 | `python3 experiments/battery_recording_session.py status`；仅在 USB 已拔且已连回家里 Wi-Fi 后使用 `start --confirm-battery-only` |
| 正常停止受控记录 | 在 USB 仍拔掉时运行 `python3 experiments/battery_recording_session.py stop`，成功后才接回 USB |
| 看本仓库改动 | `git log --oneline -8`；当前分支为 `main`，已推送到 `CUJonZhao/petring` |

串口在 USB 未接时消失是正常现象；而且打开串口可能使板子复位，因此日常查看
状态优先使用本地 HTTP 接口，不要为了查看日志而打开串口。

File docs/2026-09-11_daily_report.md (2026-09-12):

# Delta 项目日报与续接指南 — 2026-09-11

今天完成了**回家自动同步的整条软件链路**：散步时设备自己记录，回家连上家里 Wi-Fi 后自动上传，打开一个固定网址查看完整数据。
私有网站与数据服务已部署，固件已刷写，**实机端到端验证通过**：关闭 Wi-Fi 模拟外出 70 秒的记录，回家后由设备自己结束并上传，网站以相同 SHA-256 确认完整接收。
本日仍不推进佩戴或上狗测试。

## 当前成果

| 事项 | 今日结果 | 证据／入口 |
|---|---|---|
| 目标流程 | 离家自动记录 → 回家自动结束并上传 → 固定网址查看曲线、CSV、原始数据 | [同步说明](2026-09-11_home_wifi_cloud_sync.md) |
| 网站与数据服务 | 已在 ChatGPT Sites 部署（Cloudflare Workers + R2），仅所有者登录可看；分块续传接口，SHA-256／CRC 校验后才发布 | 网址见同步说明；源码在本地 `site/`（独立仓库，未包含在本仓库） |
| 固件自动上传 | 离家约 10 秒开始记录，开机 30 秒宽限，回家稳定 15 秒后自动结束，最新一段优先上传，失败分级重试 | [cloud_sync.cpp](../firmware/imu_raw_stream/src/cloud_sync.cpp) |
| 存储策略（用户确认） | 只删除网站已确认的记录，最旧优先，仅在剩余不足约 1 小时录制时删除 | 同步说明「存储策略」 |
| 设备页面 | `/records` 新增同步面板和网址，每段标注「已上传网站／待回家上传」 | 下方截图 |
| 自动化检查 | 类型检查、主机模拟、原有编解码测试、两项浏览器测试通过 | 见「检查结果」 |
| 实机 | **通过**：模拟外出记录 `e1c527b1`（1,071 条／25,736 字节）自动上传，网站确认 SHA-256 `bdeb8523…`；同轮实测断点续传与自动清理 | `data/raw/cloud_sync_20260911/physical_final/result.json` |
| 实机修复 | 跨 HTTPS 请求保留文件描述符会导致 TLS 之后 `seek` 失败；改为每块重新打开文件定位 | [cloud_sync.cpp](../firmware/imu_raw_stream/src/cloud_sync.cpp) |
| 正式网址 | 确认为 `...yesmora.chatgpt.site`（旧地址在浏览器里会跳转），设备凭据请求返回 200、无跳转 | [同步说明](2026-09-11_home_wifi_cloud_sync.md) |

## 数据链路

```mermaid
flowchart LR
  A[离开家里 Wi-Fi 约 10 秒] --> B[板子自动开始记录<br/>约 20 Hz 写入闪存]
  B --> C[回家稳定连接 15 秒<br/>自动结束本段]
  C --> D[NTP 校时与心跳]
  D --> E[16 KiB 分块续传<br/>最新一段优先]
  E --> F[网站校验 SHA-256 与 CRC<br/>R2 保存]
  F --> G[固定网址查看<br/>曲线 / CSV / 原始数据]
  F --> H[设备写入确认标记]
  H --> I[空间不足约 1 小时时<br/>删除最旧的已确认记录]
```

外出时不需要手机、路由器或互联网；回家后也不需要连接设备热点或手动上传。设备必须保持开机直到上传完成。
没有配置网站凭据的设备保持原来的「开机即记录、不上传」行为。

## 检查中发现并修订的问题

网站、第一版同步固件和实机脚本来自上一轮会话。本轮逐项检查后修订了固件：

1. **上传后从不删除本地记录**：4 MiB 分区累计约 2 小时后会存满并停止记录。现按用户确认的策略自动清理已确认记录。
2. **每次在家开机都会产生一段几十秒的启动记录**：改为开机先等 30 秒让家里 Wi-Fi 连上。
3. **家里 Wi-Fi 短暂掉线会立即开始新记录**：改为连续断开 10 秒才开始。
4. **外出时手动「停止并保存」后会立刻自动重新开始**，导致无法停下来下载或关机：现在保持停止到下次回家。
5. **网站拒收的记录每约 90 秒重复提交**：改为标记 `.reject`，每次重启只重试一次；凭据错误 5 分钟后重试。
6. **空请求体的 POST 没有 Content-Length，且只信任一个根证书**：现显式发送 0 长度，并加入 GTS Root R1、ISRG Root X1／X2，证书验证保持开启。
7. **存储满时每个循环都尝试开始记录**（每次都遍历文件系统）：改为 30 秒退避。

## 设备页面（模拟数据）

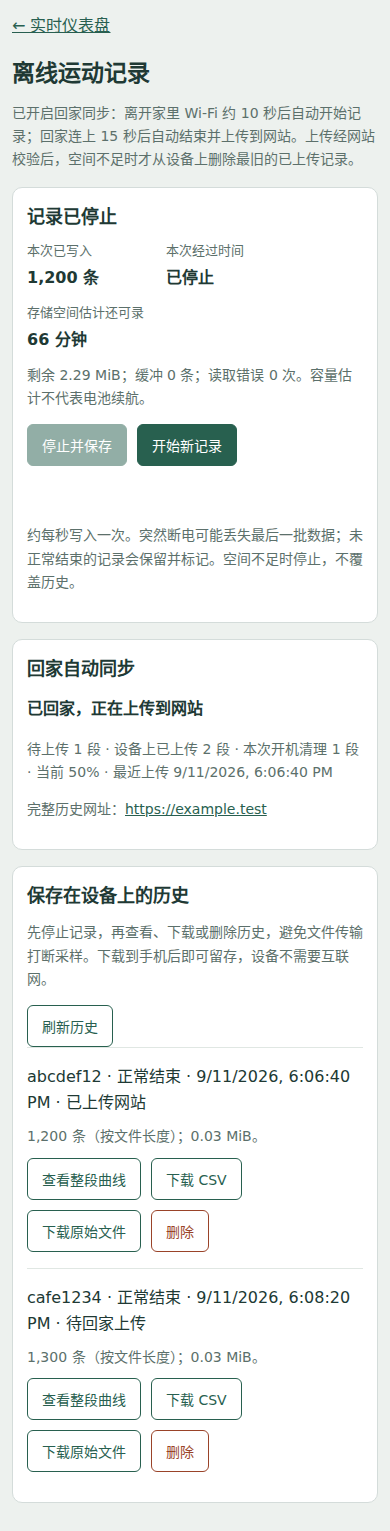
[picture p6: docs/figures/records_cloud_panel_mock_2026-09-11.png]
设备 /records 页面的回家自动同步面板，显示正在上传、待上传段数和网站网址（模拟数据）


这是浏览器测试中用模拟设备接口生成的截图，**不是真实记录**，只用于检查页面内容和 390 px 手机宽度布局。

## 检查结果

| 检查 | 结果 |
|---|---|
| C++ 类型检查（Arduino 桩头文件，gnu++11／gnu++17，`-Wall -Wextra`） | 无错误、无警告 |
| 主机模拟 `tests/cloud_sync_sim/run.sh` | 通过：只删已确认记录、最旧优先、达到 2.3 MB 即停；未确认和正在记录的文件不删；孤立标记被清理；最新一段优先上传；`.retry` 跳过、`.reject` 计数 |
| 原有编解码测试 `tests/test_offline_log.py` | 5 项通过 |
| 浏览器测试 `tests/records_page_test.cjs` | 通过（未配置同步时页面行为不变） |
| 同步面板 `tests/records_cloud_panel_test.cjs` | 通过，无横向溢出、无页面错误 |
| ESP32 编译与常规刷写（保留数据分区） | 通过，写入校验通过 |
| 实机自动记录→自动结束→自动上传→网站确认 | 通过（`physical_final/result.json`，三次运行日志无 `ERROR`／HTTP 错误） |
| 实机断点续传 | 通过：1.75 MiB 旧记录从第 65,536 字节继续 |
| 实机自动清理 | 通过：删除已确认的 `20cd0468`（6,008 字节） |
| 一小时电池续航、真实出门 | **尚未进行** |

桩头文件只模拟 arduino-esp32 2.0.x 的接口签名，不能替代 PlatformIO 编译；主机模拟不包含 TLS、Wi-Fi 和真实闪存时序。

## 实机实测数据

| 项目 | 实测 |
|---|---|
| 项目 | 首次实机（改动前） | 两次复测（改动后） |
|---|---|---|
| 外出采样 | 15.22 Hz | **19.46 / 19.43 Hz** |
| 未覆盖时间 | 28.5%（61 段间隔／70 秒） | **3.1% / 3.7%**（13 段／79 秒、16 段／76 秒） |
| 最大采样间隔 | 760 ms | 366 / 325 ms |
| 一段外出记录 | 1,071 条 | 1,543 条、1,470 条 |
| 上传请求阻塞 | 中位 4.8 秒、p90 10.3 秒 | 首个（含握手）8.0–9.7 秒，之后约 4.2 秒 |
| 回家自动结束 | 恢复 Wi-Fi 后约 26 秒 | 同上 |
| 电池电压 | 4.202 V（USB 供电，未做续航测试） | — |

三次运行的网站回执都确认了相同的 SHA-256。两次复测之间，板子自己把 10 段共 2.30 MiB 积压全部传完，并按策略删除了已确认的旧记录（含 1.75 MiB 的 `82ce2b54`），复测开始时待上传为 0——存储策略在实机上按预期工作。

## 针对首次实测的两项改动

1. **采样间隙**：定位到每次落盘都会调用一次遍历整个文件系统的剩余空间统计，分区越满越慢（近空盘 133 ms → 半满 317 ms），间隙节奏与每秒落盘一致，与 Wi-Fi 无关。改为缓存估计值（空间充足 30 秒刷新一次，接近保留区 5 秒一次），真实写入失败仍会停止记录并复核。**复测确认采样回到 19.4 Hz。**
2. **上传速度**：改为复用同一个 TLS 连接。**复测显示握手确实省掉了，但每个请求仍约 4.2 秒，且与请求体大小无关**（0 字节的 complete 请求也要 4.6 秒）。随后从同一家庭网络的 Mac 测同一接口：新建连接 1,009 ms、复用连接 879 ms，说明**约 3.3 秒耗在板子这侧**。
3. **上传速度（已解决）**：先怀疑射频省电，实测无效并撤销；加上「每请求耗时 + 是否复用 + 网站的 Connection 回答」日志后，看到 `reused=0` 而网站回的是 `keep-alive`，于是查这版 Arduino 核心的 `HTTPClient` 源码：`end()` 保留 socket 却不清空内部 client 指针，紧接着对象析构无条件 `stop()`，把刚保留的连接关掉了。改成常驻成员后实测**新建连接约 4.0 秒、复用连接 1.01 秒**，与 Mac 的 0.9 秒持平。一小时记录的上传时间由此从约 7.8 分钟降到约 1.9 分钟。

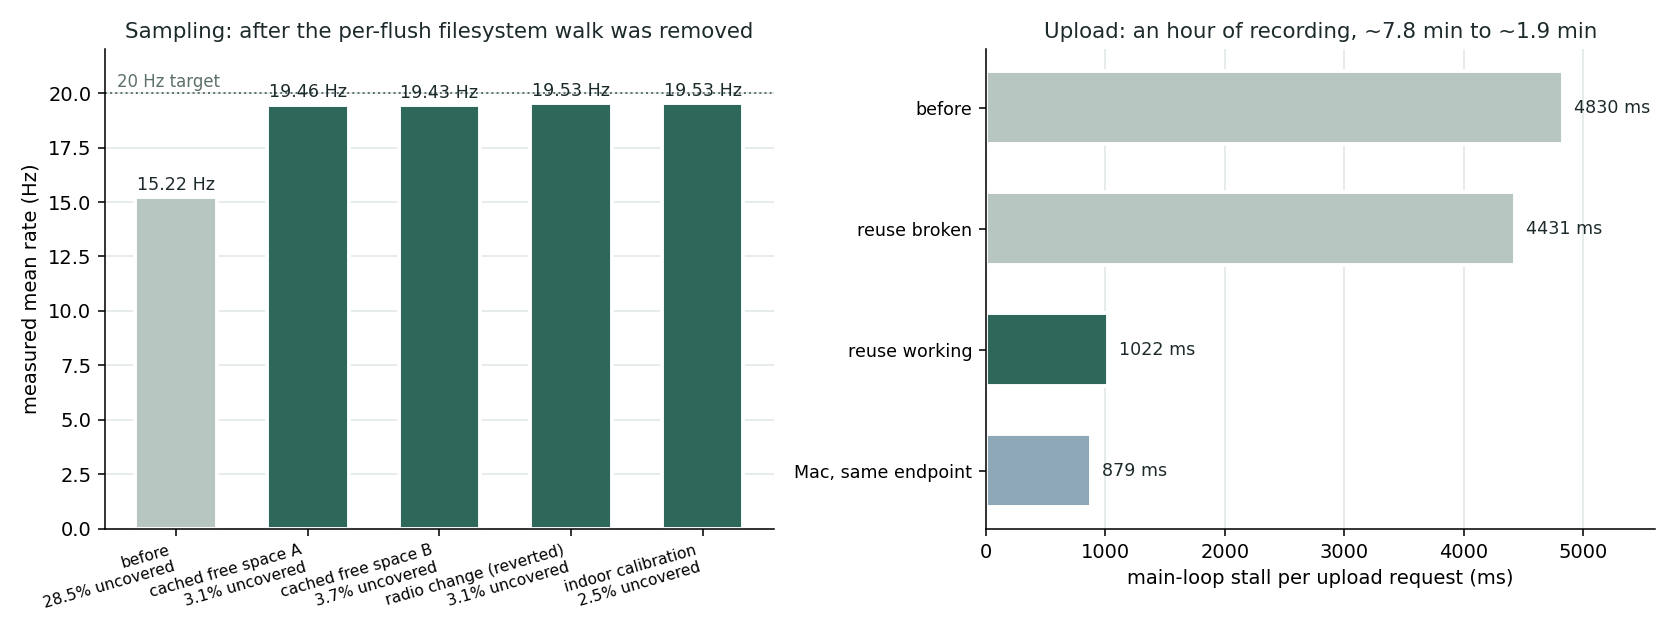
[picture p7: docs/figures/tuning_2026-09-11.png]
采样与上传的改动前后对比


左：去掉每次落盘的文件系统遍历后，采样从 15.22 Hz 回到 19.4–19.5 Hz，未覆盖时间从 28.5% 降到 2.5–3.7%。
右：每个上传请求阻塞主循环的时间，从 4,830 ms 降到 1,022 ms，已经接近 Mac 在同一接口上的 879 ms——也就是说板子这侧的额外开销基本消除，剩下的是网站本身的响应时间。「复用连接失效」那一条是中途的错误尝试：`HTTPClient` 析构时关掉了刚保留的 socket。

两张图都可以用 `python3 experiments/plot_2026-09-11.py` 从已提交的汇总数据重新生成，原始记录不需要在场。

## 网站侧核对

登录网站后逐项确认：共 **17 段、2.50 MB**，包含设备本地已经清理掉的旧记录，说明网站确实是完整历史而设备只留近期。列表接口 409 ms，设备心跳在线。
最大的一段（旧固件遗留，73,119 条、约 71 分钟、1.75 MiB）详情接口 1.53 秒、CSV 导出 1.16 秒共 73,119 行、原始文件下载正常——**一小时散步正是这个量级，之前担心的平台 CPU 限制问题不存在**。
最新一段 1,543 条的网页显示「未覆盖 2.8 秒」，与设备端实测的 3.1% 吻合；旧固件那段是 19.6%，对比明显。
小问题：网站导出的 CSV 用完整浮点精度（会出现 `-0.35000000000000003`），比设备端导出大约大 50%，属于可改进项，需要在 Codex 中改并部署。

## 活动分析（离线，尚未标定）

`experiments/gait_analysis.py` 从一段记录算出：静止／走／跑的时间预算、相对活动指数、步频曲线和图。方法是 4 秒窗口、2 秒步进，特征为合加速度的 MAD（平均振幅偏差，毫 g）、ENMO、陀螺仪幅度，以及 0.5–5 Hz 带内的主频与周期性。20 Hz 采样的奈奎斯特是 10 Hz，足以分辨 1–4 Hz 的步频。

在 20 Hz 下 MAD 比 ENMO 区分度好得多：桌面实测中，手动摆弄板子时 MAD 约 100 mg、静止 0.7 mg，而两者的平均 ENMO 都低于 30 mg。因此分类和活动指数都用 MAD，ENMO 仅作为与人体加速度计文献对照的参考值。

**当前阈值是占位值，没有标定。** 需要一段带标签的数据（`--labels` 加 `--suggest` 会给出分界建议并输出混淆矩阵）。另外：加速度计不能测能量消耗，行业做法是先用间接测热法把活动计数回归到实测能耗上，且随设备与佩戴位置而变；所以这里只给相对活动指数，不给千卡。

## 网站端分析（已写好，待部署）

用户的目标状态是：把盒子绑在胸背上带出门，回来登录网站就能看到数据和分析，中间不碰任何按钮。为此把离线脚本的算法移植成 `site/lib/gait.ts`，在**上传时算一次**并随记录存储（页面详情里也会重算，所以此前已上传的记录同样能看到），页面上新增静止／走路／跑动时长、活动指数，以及按状态着色的曲线底色。移植后用同一批台面数据对拍，TypeScript 与 Python 的时间预算和指数完全一致。

网站只能在 Codex 里部署，所以这部分需要用户先本地 `npx tsc --noEmit && npm run build` 验证，再在 Codex 中部署。

## 晚间：运动触发与第一次真实标定

用户明确了目标状态：**盒子绑在狗的胸背上，出门遛狗，回来登录网站就有数据和分析，中间不碰任何按钮**。由此做了两处改动并在实机上验证。

### 记录触发方式

住处 Wi-Fi 全覆盖，走到楼下也还在信号范围内，所以「离开 Wi-Fi」这一个触发不够。新增：在家范围内**持续活动约 30 秒**也开始记录，**静止 5 分钟**后自动结束。离开 Wi-Fi 的记录不受静止规则影响（狗中途休息不会被切成两段），手动开始的记录仍完全由用户控制。记录头的保留字节里保存触发原因（`w`/`m`/`u`）。

### 闭环实测（2026-09-11 23:15，室内，全程未离开家里 Wi-Fi）

| 环节 | 结果 |
|---|---|
| 触发 | 记录头触发字节 `m`，运动触发 |
| 开始／结束 | 23:15:43 开始；静止 5 分钟后自动结束，状态 `complete` |
| 采样 | 6,724 条，5.7 分钟，**19.53 Hz**，未覆盖 2.0 秒 |
| 上传 | 23:21:49 自动完成，网站收录（共 19 段） |
| 电池 | 3.878 → 3.882 V（电池供电，6 分钟内无可测下降） |

**用户全程只是走动和把板子放下，没有按任何按钮。** 这是目标闭环第一次在无人干预下完整跑通，只差「戴在狗身上」和「网站端分析上线」。

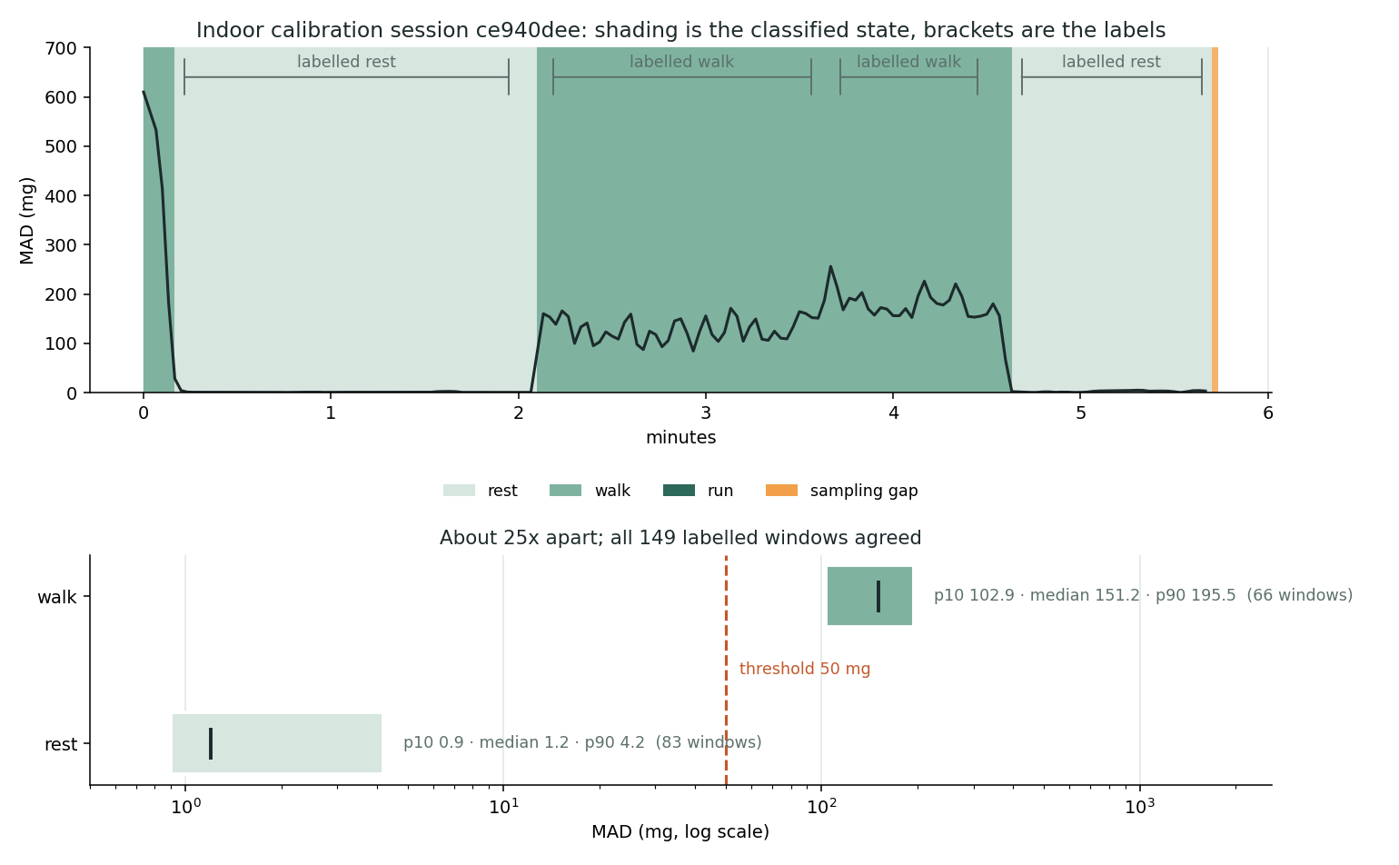
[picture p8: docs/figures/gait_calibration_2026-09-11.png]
室内标定记录：底色为自动判定状态，下方为两类的 MAD 分布


上图来自真实记录 `ce940dee`。底色是设备算法判定的状态，上方括号是人工标注的动作段；下半部分是两类的 MAD 分布（对数轴），虚线是最终采用的 50 mg 阈值。

### 走／静止阈值标定

动作序列：触发用的走动 → 静止 2 分钟 → 正常走约 1.5 分钟 → 快走约 1 分钟 → 静止至自动结束。板子**端在身前、手臂不摆动**。

| 标签 | 窗口数 | MAD p10 | 中位 | p90 |
|---|---|---|---|---|
| 静止 | 83 | 0.9 mg | 1.2 mg | 4.2 mg |
| 走路 | 66 | 102.9 mg | 151.2 mg | 195.5 mg |

两类相差约 25 倍，**149 个有标签窗口全部分类正确**。阈值定为 50 mg，离线脚本与 `site/lib/gait.ts` 同步更新。
**跑步阈值仍未标定**（没有跑的数据），600 mg 是猜测值，代码与档案中均已注明。
标定档案：`experiments/results/gait_calibration_2026-09-11.json`。

### 频率特征不可用于手持场景

| 分段 | FFT 主峰 | 自相关 | 振幅 |
|---|---|---|---|
| 正常走 | 3.38 Hz | 2.86 Hz | 105–163 mg |
| 快走 | 1.88 Hz | 2.00 Hz | 165–204 mg |

两种估计方法一致，所以不是算法挑错谐波。快走的 2.0 Hz 即 120 步/分，是真实步频；正常走的约 3 Hz 太快，不可能是步频——端在身前时手臂构成弹簧，其 2–5 Hz 晃动在躯干起伏较小时盖过了步频。**该频率反映的是携带方式，不是步态**，因此分类改为只用振幅（振幅排序正确：快走 > 正常走 > 静止），频率降级为诊断量。

胸背固定是刚性耦合到躯干的，预期主频就是步频；**第一次佩戴记录回来后要专门复核这一点**，若频率变可靠，跑步判定可同时使用振幅与步频。

另外修了一个假阳性：放下板子瞬间的单个 610 mg 窗口被判为「跑」，现在首尾窗口跟随相邻窗口。

## 限制与风险

- 网站托管在 ChatGPT Sites：修改网站需要在 Codex／ChatGPT 中部署；Claude 会话无法访问或部署该网站。
- 网站的分块接口会检查 `content-length` 请求头；如果托管平台的代理去掉这个头，上传会返回 400。实机验证会暴露这个问题，修复需要改 `site/` 并重新部署。
- 单段最大 4 MiB，网站在一次请求中组装并解码；托管平台 CPU 限制下的大文件表现未实测。
- 外出时设备热点常开并每 15 秒尝试重连，会增加耗电；一小时续航仍未测。
- Sites 访问令牌过期后需要重新授权并写入设备。
- 采样仍受同步闪存写入影响，不是严格恒定 20 Hz；时间戳如实保留间隙。

## 下次从这里继续

1. **在 Codex 中部署 `site/`**（含标定后的阈值与分析面板）。本机 `npx`／node 不在登录 shell 的 PATH 中，`bash experiments/cloud_sync_mac.sh sitecheck` 会自动寻找 node；找不到时直接由 Codex 构建部署。部署后那段记录应显示「走路 2 分 42 秒 · 跑动 0 秒 · 活动指数 80 mg」，与离线脚本一致。
2. **把盒子绑在 Delta 的胸背上遛一次**。回来后重点看三件事：刚性固定下频率是否变成可用的步频；狗的振幅区间落在哪里（据此重新标定走／跑）；整趟的电池消耗。分析命令：
   `python3 experiments/gait_analysis.py <记录>.bin --plot ... --windows-csv ...`，带标签时再加 `--labels ... --suggest`。
3. 一小时电池记录；评估外出时是否关闭热点以省电。
4. 采样已恢复到 19.5 Hz，剩余约 3% 未覆盖时间来自落盘本身，暂不处理。
5. 可选：运动触发会丢掉开头约 30 秒，如需补上可用板上 2 MiB PSRAM 做预缓冲；网站导出的 CSV 用完整浮点精度，比设备端大约 50%。
6. 后台还有一个 9 月 11 日 17:47 启动的本地开发服务器在跑，部署完可在该窗口 Ctrl-C 关掉。

## 明天开工速查

| 项 | 现状 |
|---|---|
| 板子固件 | 与仓库当前固件源码一致（最后一次刷写 2026-09-11 23:00，含运动触发、静止结束、采样修复、连接复用） |
| 网站 | 线上是旧版，**分析面板与标定阈值尚未部署**；代码在本机 `site/`（独立仓库，2 个本地提交，无远端） |
| 父仓库 | 本地领先 origin 若干提交，用 `git push` 推送 |
| 网址 | https://delta-walk-jz-20260911.yesmora.chatgpt.site （旧的 `fit-siren-4693` 主机会跳转，设备配置里已改） |
| 设备凭据／整片备份 | `data/raw/cloud_sync_20260911/secrets.config.json`、`before_flash.bin`（被 .gitignore 排除，勿提交） |
| 今晚的标定记录 | `data/raw/cloud_sync_20260911/indoor_labeled/`（原始 bin、窗口 CSV、标签），汇总已提交到 `experiments/results/` |
| 阈值住在两个地方 | `experiments/gait_analysis.py` 的 `DEFAULT_THRESHOLDS` 与 `site/lib/gait.ts` 的 `THRESHOLDS`，**改一处必须同步另一处**，改完跑一次对拍 |

常用命令（都在仓库根目录）：

```sh
bash experiments/cloud_sync_mac.sh flash       # 编译并刷写（保留数据分区）
bash experiments/cloud_sync_mac.sh cloudtest   # 1 分钟：三次只读请求的耗时
bash experiments/cloud_sync_mac.sh validate    # 完整实机验证（关 Wi-Fi 模拟外出）
bash experiments/cloud_sync_mac.sh sitecheck   # 网站类型检查与构建（自己找 node）
sh firmware/imu_raw_stream/tests/cloud_sync_sim/run.sh   # 主机模拟与公开接口检查
python3 experiments/gait_analysis.py <记录>.bin --plot out.png --windows-csv out.csv
python3 experiments/gait_analysis.py <记录>.bin --labels labels.csv --suggest
python3 experiments/analyze_cloud_sync_run.py <运行目录>
python3 experiments/plot_2026-09-11.py         # 重新生成本报告的图
```

环境上的坑（都遇到过）：

- `npx`／`node` 不在登录 shell 的 PATH 里，`sitecheck` 会去常见安装位置找；找不到就在 Codex 里构建部署。
- PlatformIO 装在 `/tmp/petring-firmware-env/bin/pio`，重启后可能消失，脚本里有回退逻辑。
- 串口是 `/dev/cu.usbserial-59680111041`；板子不插 USB 时 `probe` 会报 `No such file or directory`，属正常。
- 网站只能在 Codex／ChatGPT Sites 中部署，Claude 会话既连不上也部署不了。
- 打开串口会让板子复位，复位后发的命令会丢，脚本里已等待启动完成。

## 今天归档的文件

| 类别 | 文件 |
|---|---|
| 同步固件 | [cloud_sync.h](../firmware/imu_raw_stream/src/cloud_sync.h)、[cloud_sync.cpp](../firmware/imu_raw_stream/src/cloud_sync.cpp)、[根证书](../firmware/imu_raw_stream/src/cloud_ca.h)、[main.cpp](../firmware/imu_raw_stream/src/main.cpp)、[记录器](../firmware/imu_raw_stream/src/motion_logger.cpp)、[手机页面](../firmware/imu_raw_stream/src/records_page.h) |
| Mac 脚本与实机验证 | [cloud_sync_mac.sh](../experiments/cloud_sync_mac.sh)、[validate_cloud_sync.py](../experiments/validate_cloud_sync.py) |
| 自动化检查 | [主机模拟](../firmware/imu_raw_stream/tests/cloud_sync_sim/)、[同步面板浏览器测试](../firmware/imu_raw_stream/tests/records_cloud_panel_test.cjs) |
| 实机分析工具 | [运行分析](../experiments/analyze_cloud_sync_run.py)、[网站延迟测量](../experiments/measure_cloud_latency.py)、[串口计时探测](../experiments/cloud_self_test.py) |
| 活动分析（离线） | [步态与活动量分析](../experiments/gait_analysis.py)、[标定档案](../experiments/results/gait_calibration_2026-09-11.json) |
| 网站端分析 | `site/lib/gait.ts`、`site/app/dashboard.tsx`（独立仓库，未推送到 GitHub） |
| 说明 | [同步说明](2026-09-11_home_wifi_cloud_sync.md)、[固件说明](../firmware/imu_raw_stream/README.md) |

网站凭据和刷写前的整片备份留在本地 `data/raw/cloud_sync_20260911/`，由 `.gitignore` 排除，不可提交或公开。
网站源码 `site/` 是独立的 Sites 仓库，本仓库忽略该目录，因此不在 GitHub 上。

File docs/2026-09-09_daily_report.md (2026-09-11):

# Delta 项目日报与续接指南 — 2026-09-09

今天完成了 **v0.4 实物组装、离线运动记录固件、手机网页历史查看，以及第一次断开 Wi-Fi 的实机短测**。
设备现在能将运动样本保存在板载闪存，恢复网络后下载完整记录。
本日以软件、装配和桌面验证收尾，暂不推进佩戴或上狗测试。

## 当前成果

| 事项 | 今日结果 | 证据／入口 |
|---|---|---|
| 外壳 | 用户确认 v0.4 打印、组装完成；照片可见合盖、交叉魔术贴和外置开关 | [组装照片](../hardware/reference_images/stage1b_v0_4_assembled_2026-09-09.jpg)、[结构与打印文件](../hardware/enclosure/v0_4/README.md) |
| 产品方向 | 因当前体积，探索胸背式遛狗活动记录；优先解决记录和回看 | 本报告及 [开发交接](2026-09-09_offline_motion_logging.md) |
| 离线记录 | 开机自动创建新记录；20 Hz 目标采样，批量写入独立 4 MiB 闪存区 | [固件说明](../firmware/imu_raw_stream/README.md) |
| 手机查看 | 浏览器可停止／开始、列出历史、查看整段曲线、下载 CSV／原始文件 | [真实手机页面](figures/offline_report_mobile_2026-09-09.png) |
| 升级与保留 | 完整备份 8 MB 闪存后升级；原有 560 条电池日志逐行保留 | [升级与实机报告](../experiments/offline_usb_bench_2026-09-09.md) |
| 两分钟实机 | 2,279 条样本，关闭 Wi-Fi 后仍增长，CSV 与二进制一致，重启后旧文件不变 | 主记录 `f35506a5` |

## 组装状态

用户完成的白色 v0.4 外壳，交叉魔术贴保持盖子，开关位于盒外

这是用户提供的实物照片。当前外壳沿用已发布的 v0.4 CAD：底盒约 65.25 × 65.25 × 21.36 mm，合盖名义外尺寸约 69.05 × 69.05 × 22.96 mm。
照片确认了整体装配外观；实际螺钉规格、电池内部固定方式、保持力、防水和佩戴舒适性没有在本轮单独验证。
IMU 保持既有背面机械卡持，组合总高仍采用用户确认的 16.36 mm；没有为本次工作强行拆出。

已有文件继续复用：[完整打印包](../hardware/enclosure/print_packages/delta_collar_v0_4_fit_print_20260909.zip)、[摆放与绕线图](../hardware/enclosure/v0_4/placement_routing.png)、[测量记录](2026-09-08_stage1b_caliper_measurements.md)。本轮没有改动 STL。

## 数据链路已补齐到哪里

```mermaid
flowchart LR
  A[Feather + IMU 采样] --> B[板载闪存保存]
  B --> C[停止并保存本次记录]
  C --> D[手机与设备连接]
  D --> E[浏览器查看曲线 / 下载 CSV]
```

记录阶段不要求家庭 Wi-Fi、手机持续连接或互联网。回看时可使用设备热点，或让手机与设备处于同一家庭局域网。
这里的网页由设备提供，**云端网站上传、专用手机 App 和蓝牙同步尚未实现**。

- 每条 24 字节，保留原始六轴计数、相对时间、IMU 温度、电压及简单活动分数／状态；文件头 32 字节，每条带 CRC。
- 按 20 Hz 计算，一小时约 1,728,032 字节，另计文件系统开销。容量足以作为一小时记录方案的基础，但还不是续航实测结果。
- 正常停止会保存剩余缓冲。未正常结束的文件保留并标记；空间不足停止，不自动覆盖历史。
- 大文件下载在停止记录后进行；CSV 导出校验数据，手机页面再次核对行数，避免把截断下载当成完整文件。
- 自动开机记录只有相对时间；从手机按“开始新记录”时，会附带手机当前日历时间。没有伪造离线时钟。

## 真实设备页面

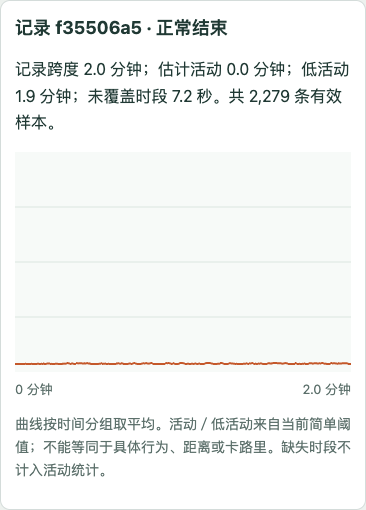
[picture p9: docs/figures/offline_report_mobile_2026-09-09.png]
真实设备两分钟记录的手机尺寸曲线，显示 2279 条有效样本和约 7.2 秒未覆盖时间


这张图来自真实板子的主测试记录，非合成演示数据。设备处于桌面，曲线低活动符合本次场景；它不能用于确认走路、跑步或犬类行为分类效果。

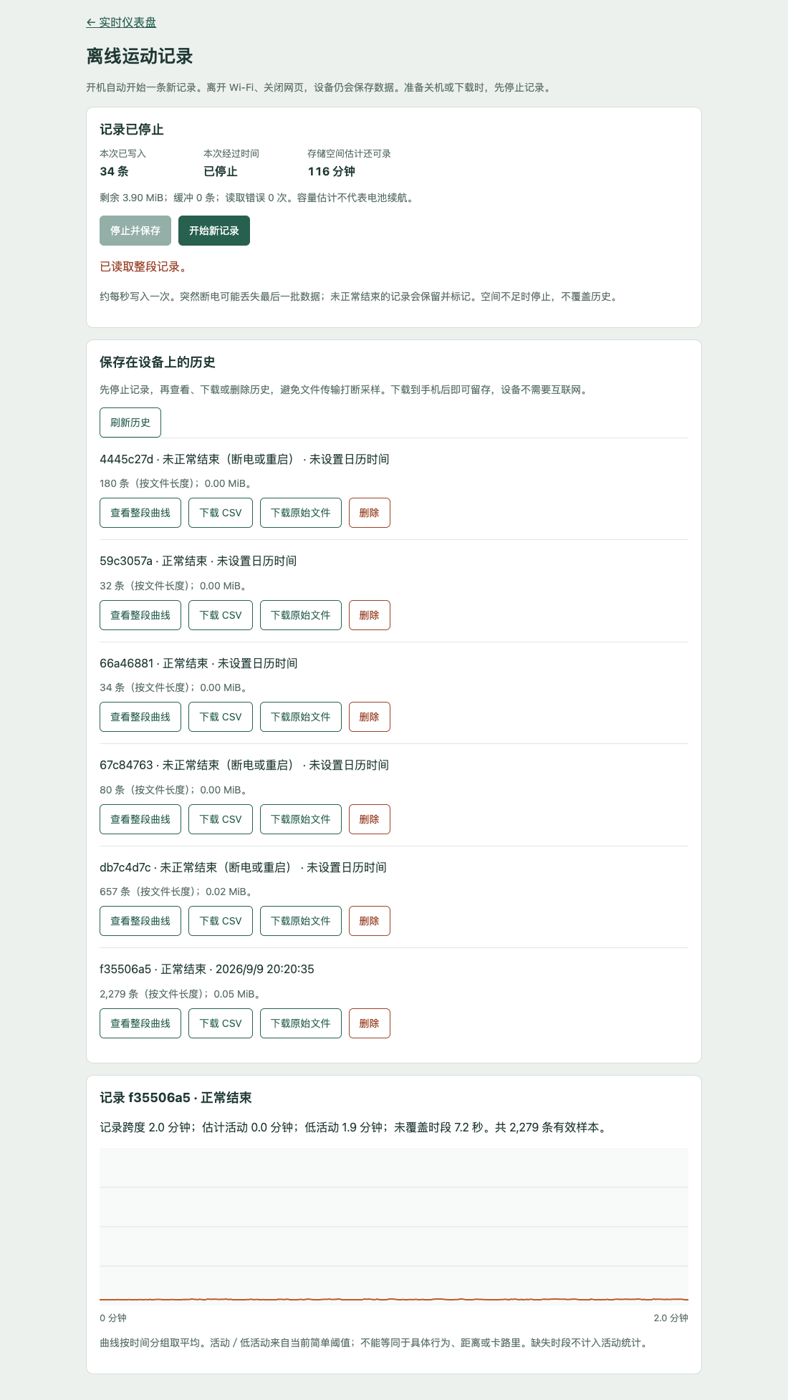
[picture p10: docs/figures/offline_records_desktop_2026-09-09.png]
真实设备的桌面历史记录页面


列表中有几条启动、串口连接和复位产生的短记录；`interrupted` 表示没有正常按停止结束，不等同于全部数据损坏。
本次主要两分钟记录是 **`f35506a5`**；专门用于复位恢复的记录是 **`67c84763`**。

## 实测数据与限制

真实两分钟离线采集及采样间隔图

图上半部按下载文件中的样本时间戳重建累计样本数；绿色区间从关闭无线命令到确认重连，包含重连过程，事件时刻与样本时刻可能有请求延迟量级的偏差。
下半部展示每秒内最大的相邻采样间隔。它显示了一个需要后续改进的限制：**同步闪存写入会阻塞采样，当前并非严格恒定的 20 Hz**。

| 检查 | 实测 |
|---|---|
| 记录跨度／样本数 | 120.093 秒／2,279 条 |
| 平均频率／间隔中位数 | 18.973 Hz／50 ms |
| 最大间隔 | 387 ms |
| 大于 100 ms 的间隔 | 54 段，合计 7.202 秒 |
| 网页未覆盖时间 | 约 7.2 秒，包含初始 30 ms；不计作活动或静止 |
| 关闭无线期间 | 写入计数从 560 增至 1,140；HTTP 不可达时串口仍确认正在记录 |
| CSV 与原始数据 | 行数一致，时间戳／状态／数值逐条核对通过 |
| 正常记录重启保持 | 重新下载后逐字节相同 |
| 未停止记录的 EN 复位 | 80 条已同步样本恢复，状态为未正常结束 |
| 固件错误 | 测试未发现 `ERROR`，读取错误计数为 0 |

原始文件 54,728 字节。详细方法、哈希、温度范围、备份和串口速度见 [实机报告](../experiments/offline_usb_bench_2026-09-09.md)。
**USB 短测不等同于一小时电池续航，EN 复位也不等同于切断供电。** 实际写满停止、直接断电尾部恢复仍待验证。

## 今天归档的文件

| 类别 | 文件 |
|---|---|
| 固件与分区 | [main.cpp](../firmware/imu_raw_stream/src/main.cpp)、[记录器](../firmware/imu_raw_stream/src/motion_logger.cpp)、[数据格式](../firmware/imu_raw_stream/src/motion_format.h)、[分区表](../firmware/imu_raw_stream/partitions.csv) |
| 手机页面 | [records_page.h](../firmware/imu_raw_stream/src/records_page.h) |
| 解码与实机验证 | [独立解码工具](../experiments/decode_motion_log.py)、[USB 验证脚本](../experiments/validate_offline_recorder.py) |
| 自动化检查 | [主机测试](../firmware/imu_raw_stream/tests/test_offline_log.py)、[浏览器测试](../firmware/imu_raw_stream/tests/records_page_test.cjs) |
| 数据图复现 | [汇总 JSON](../experiments/results/offline_usb_bench_2026-09-09_summary.json)、[绘图脚本](../experiments/plot_offline_bench.py)、[SVG](figures/offline_usb_bench_2026-09-09.svg) |
| 开发环境与操作 | [固件说明](../firmware/imu_raw_stream/README.md)、[实验依赖](../experiments/requirements.txt) |

图可直接从已提交的汇总 JSON 重新生成：安装 `experiments/requirements.txt` 后，在仓库根目录运行 `python experiments/plot_offline_bench.py`。
汇总数据使用真实短测结果；主机测试中的 72,000 条合成样本只用于格式／下载流程验证，没有混入实测图。

整片闪存备份、含设备设置的文件、原始串口日志与完整 CSV/BIN 留在本地 `data/raw/offline_upgrade_20260909_201050/`，由 `.gitignore` 排除。
GitHub 收录代码、报告、实物／界面图片和可复现的汇总数据。新克隆能看报告与重画图，但不会自动得到设备原始备份。

## 下次从这里继续

1. 测试结束时设备已停止记录、无线已恢复；重新开机会自动开始新记录。需要回看时进入设备 `/records`；局域网地址可能随网络变化。
2. 下一项验证是一小时桌面电池记录，检查完整文件、采样间隙、实际存储占用和电压趋势。
3. 如要做更严格的固定频率分析，先解耦采样与闪存写入，再比较间隔分布；本次没有为了报告修改已验证的采样实现。
4. 单独验证直接断电、存储写满和离开家庭网络时的热点自动恢复。
5. 用户明确暂缓佩戴和上狗；后续行为标签采集、算法改进和胸背固定方案，在用户恢复该方向后继续。

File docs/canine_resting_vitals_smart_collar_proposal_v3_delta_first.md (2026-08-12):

# Project Proposal - Stage 1 Engineering Plan v3

# Delta Rest & Activity Smart Collar Prototype

Delta-first 狗狗睡眠/活动记录智能项圈 - ESP32 + IMU + Wi-Fi Dashboard 第一阶段工程计划书

本项目的真实目标不是先做一个完整产业化设备，而是先发明并做出一款 Delta 能舒服佩戴、能在家中真实使用的智能项圈原型。第一阶段聚焦几个小时的无线睡眠/活动实验记录：用现有 ESP32 Feather/HUZZAH32 V2、Feather OLED、IMU、电池和浏览器 dashboard，验证佩戴舒适性、无线数据链路、活动/休息识别和实验日志。后续再逐步扩展呼吸、心率趋势、手机 App 和订阅式服务。

## 0. 当前需求理解

| 维度 | 已确认决策 |
|---|---|
| 第一目标 | 做出真实可用的产品原型，先给家里的狗 Delta 使用 |
| 使用对象 | Delta，4 个月喜乐蒂犬，约 7.5 kg，长毛，愿意戴项圈，暂无健康问题 |
| 第一优先功能 | 睡眠/活动记录，而不是先做心率/呼吸 |
| 实验尺度 | 先做几个小时实验记录，再升级优化 |
| 佩戴原则 | 舒适和安全优先，数据质量第二 |
| 模块位置 | 倾向项圈下方贴合，为后续呼吸/心率预留条件 |
| 外壳方式 | 第一版手工原型，不先做 3D 打印 |
| 数据方式 | 不能插线拖电脑，优先无线实时监控 |
| 电脑端 | 先做浏览器网页 dashboard，后续再迁移手机 App |
| 无线通信 | 第一版用 ESP32 连接家里 Wi-Fi |
| 现有硬件 | ESP32 Feather/HUZZAH32 V2、Feather monochrome 128x32 OLED |
| 电池 | 暂无 LiPo，第一阶段可接受 400-800 mAh 小电池 |
| 第一阶段传感器 | 推荐 IMU + 电池 + OLED，预留 piezo/温度/呼吸/心率扩展 |

## 1. 项目定位

本项目第一阶段定位为 Delta-first engineering prototype。它不是医疗诊断设备，也不是一开始就面向大规模销售的量产项圈，而是一款面向真实家庭使用的实验型智能项圈模块。

第一阶段的产品定义：

> 一个 Delta 愿意佩戴几个小时、能无线显示并记录活动/休息状态的下方贴合式项圈模块。

第一阶段不追求漂亮外壳、长期续航、完整手机 App 或医疗级准确性。真正要验证的是：

- Delta 是否愿意佩戴；
- 下方贴合模块是否安全、轻、不可轻易啃咬；
- IMU 数据是否能区分走动、玩耍、趴下、睡觉/休息；
- Wi-Fi dashboard 是否能稳定实时显示并保存 CSV；
- 这个硬件结构是否能为后续呼吸/心率扩展留下空间。

## 2. 第一阶段范围

| 第一阶段包含 | 第一阶段不包含 |
|---|---|
| ESP32 Feather V2 无线数据采集 | GPS 或蜂窝通信 |
| IMU 活动/休息记录 | 医疗诊断 |
| OLED 本地状态显示 | 准确心率测量 |
| Wi-Fi 浏览器 dashboard | 准确呼吸率测量 |
| CSV 实验日志保存 | 长期无人值守续航 |
| 电池供电佩戴测试 | 防水量产外壳 |
| 手工下方贴合结构 | 3D 打印或注塑外壳 |
| 后续传感器接口预留 | App Store 级手机 App |

## 3. 第一阶段系统架构

| 模块 | 第一阶段方案 | 理由 |
|---|---|---|
| 主控 | 现有 ESP32 Feather/HUZZAH32 V2 | 已拥有，支持 Wi-Fi，开发快，适合第一版 |
| 显示 | 现有 Feather monochrome 128x32 OLED | 显示 IP、电池、状态、连接状态 |
| 传感器 | 6-DoF IMU，推荐 LSM6DSOX | 轻、小、便宜、I2C 连接，足够做活动/睡眠 |
| 电源 | 3.7V LiPo 500 mAh 起步 | 小型、轻量、Feather 生态兼容 |
| 连接 | STEMMA QT/Qwiic I2C cable | 少焊接，方便快速迭代 |
| 电脑端 | 浏览器 dashboard | 最快做实时曲线、状态和 CSV 保存 |
| 外壳 | 手工小盒 + 泡棉/硅胶/Velcro | 低成本验证舒适性和固定方式 |

第一阶段数据流：

| 步骤 | 数据流 |
|---|---|
| 1 | IMU 采集 ax, ay, az, gx, gy, gz |
| 2 | ESP32 计算 motion score 和当前状态 |
| 3 | ESP32 通过 Wi-Fi 推送实时数据 |
| 4 | 电脑浏览器 dashboard 显示曲线和状态 |
| 5 | dashboard 保存 CSV 实验日志 |
| 6 | 人工记录 Delta 的实际行为用于对照 |

## 4. 推荐采购清单

因为你已经有 ESP32 Feather 和 OLED，第一阶段不建议购买新主控。预算应集中在 IMU、电池、连接线和舒适固定材料。

| 优先级 | 物品 | 数量 | 估算价 | 作用 |
|---|---|---:|---:|---|
| 必买 | Adafruit LSM6DSOX 6-DoF IMU - STEMMA QT/Qwiic | 1 | $11.95 | 活动/休息识别第一传感器 |
| 必买 | 3.7V LiPo 500 mAh，JST-PH | 1 | $7.95 | 佩戴实验电源 |
| 必买 | STEMMA QT/Qwiic 4-pin cable，50 mm 或 100 mm | 2-3 | $0.95-$1.25 each | IMU 连接，便于返工 |
| 必买 | 小塑料盒/热缩管/泡棉/软硅胶片/Velcro | 若干 | $15-$30 | 手工下方贴合结构 |
| 建议买 | JST-PH 延长线、硅胶线、双面胶、扎带 | 若干 | $10-$20 | 电池和线材整理 |
| 建议买 | 备用 LiPo 350-500 mAh | 1 | $6-$8 | 多轮测试备用 |
| 暂缓 | BMI270 IMU | 0-1 | $18-$25 | 后续 BCG/心率路线对比 |
| 暂缓 | piezo ribbon/disk | 0 | $10-$30 | 后续呼吸/贴合微振动 |
| 暂缓 | 温度传感器 MCP9808 | 0 | $5 | 后续温度趋势 |
| 暂缓 | microSD module | 0 | $5-$15 | Wi-Fi dashboard 不稳定后再加 |
| 暂缓 | nRF52840 | 0 | $25 | 第二阶段低功耗/BLE 迁移 |

推荐第一阶段预算：

| 版本 | 预算 | 适用情况 |
|---|---:|---|
| 最低开工 | $35-$50 | 只买 IMU、电池、线和简单固定材料 |
| 推荐启动 | $60-$90 | 加备用线材、电池和更舒服的手工结构材料 |
| 过度采购 | 不建议超过 $150 | 第一阶段还没验证佩戴和数据，不要先买太多 |

## 5. 为什么第一阶段不先买 BMI270/nRF/piezo

BMI270、nRF52840 和 piezo 都有价值，但它们更适合第二阶段。第一阶段最重要的问题不是心率，而是 Delta 是否愿意戴、无线链路是否稳定、活动/睡眠数据是否可用。

| 物品 | 暂缓原因 | 后续何时购买 |
|---|---|---|
| BMI270 | 更贴近 IMU-BCG 心率探索，但第一阶段活动/休息不需要 | 当第一版佩戴和 dashboard 跑通后，用于心率/BCG 对比 |
| nRF52840 | 更接近低功耗 BLE 产品，但开发会拖慢第一版 | 当 Wi-Fi 原型证明有价值后，做低功耗版本 |
| piezo | 对呼吸和贴合微振动有价值，但增加机械复杂度 | 当下方贴合结构稳定后再加 |
| 温度传感器 | 容易加，但不是第一优先功能 | 当活动/休息记录稳定后再加 |
| microSD | 可靠性好，但第一版可由电脑 dashboard 保存 CSV | Wi-Fi 丢包明显时再加 |

## 6. 佩戴结构方案

Delta 是 4 个月、7.5 kg、长毛喜乐蒂。长毛会降低贴合信号质量，但第一阶段只做活动/睡眠，不需要强压贴合。结构设计应优先舒适、安全、低晃动和防啃咬。

第一版结构原则：

- 模块尽量接近吊牌大小，但允许略大于吊牌，因为 Feather 本身不小；
- 位置在项圈下方靠近喉咙，但只轻贴，不压迫；
- 外表面平滑，无裸露线材、硬边或可咬凸起；
- 模块和 IMU 要固定在一起，避免 IMU 在盒内松动；
- 用泡棉或软硅胶接触项圈/毛发区域，减少硬物压迫；
- 先用 Velcro/弹性带可拆卸固定，不做永久固定。

建议装配：

| 部位 | 做法 |
|---|---|
| ESP32 + OLED | 放入小盒或热缩保护层，保留 USB-C 充电入口 |
| IMU | 固定在盒内靠近项圈一侧，和盒体刚性连接 |
| 电池 | 放在盒内或盒背，用泡棉隔开，不能被挤压或折弯 |
| 线材 | 全部收进盒内或热缩管内，外部不留可咬线 |
| 接触面 | 加软泡棉/硅胶垫，轻贴毛发，不追求压紧皮肤 |
| 固定 | Velcro 穿过项圈或绕项圈固定，便于快速拆卸 |

安全底线：

- 第一次佩戴只做 5-10 分钟；
- 佩戴时必须有人观察；
- 不在无人看管时给幼犬长时间佩戴；
- 不让 Delta 睡觉时佩戴尚未验证过的硬件；
- 电池不能被咬到、刺穿、弯折或压迫；
- 模块不能勒脖子，不能影响吞咽、呼吸和转头。

## 7. 固件计划

ESP32 固件第一版使用 Arduino/PlatformIO 路线，优先快跑通。

| 固件模块 | 功能 |
|---|---|
| imu_reader | 读取 ax, ay, az, gx, gy, gz |
| feature_extractor | 计算 accel magnitude、gyro magnitude、motion score |
| state_classifier | 输出 Active / Resting / Unknown |
| wifi_server | 连接家里 Wi-Fi，提供 dashboard 页面或数据接口 |
| websocket_stream | 实时发送 IMU 和状态数据 |
| oled_status | 显示 IP、电池、Wi-Fi、当前状态 |
| battery_monitor | 读取电池电压，估算电量 |
| config | Wi-Fi 名称、密码、采样率、阈值 |

第一版采样建议：

| 用途 | 采样率 |
|---|---:|
| 活动/休息识别 | 25-50 Hz |
| 实时 dashboard 曲线 | 10-25 Hz 显示即可 |
| 原始 CSV 保存 | 25-50 Hz |
| 后续呼吸探索 | 25-100 Hz |
| 后续心率/BCG | 100-400 Hz，再升级传感器/结构 |

第一版状态规则：

| 状态 | 判断逻辑 |
|---|---|
| Active | motion score 连续高于阈值 |
| Resting | motion score 连续低于阈值 2-5 分钟 |
| Unknown | 刚切换、数据不足、信号异常或中间状态 |

## 8. 浏览器 Dashboard 计划

第一版 dashboard 运行在电脑浏览器中。ESP32 连接家里 Wi-Fi 后，OLED 显示 IP 地址，电脑访问该 IP 即可查看页面。

第一版页面内容：

| 区域 | 内容 |
|---|---|
| Header | Delta Collar Prototype、连接状态、设备 IP |
| Current State | Active / Resting / Unknown |
| Live Motion | motion score 实时曲线 |
| Raw IMU | ax, ay, az, gx, gy, gz 可选显示 |
| Battery | 电池电压和估算电量 |
| Session Controls | Start Recording / Stop / Export CSV |
| Notes | 手动输入实验备注，如 sleeping, walking, playing |

CSV 字段：

| 字段 | 说明 |
|---|---|
| timestamp_ms | ESP32 时间戳 |
| host_time | 电脑记录时间 |
| ax, ay, az | 加速度 |
| gx, gy, gz | 角速度 |
| accel_mag | 加速度模长 |
| gyro_mag | 角速度模长 |
| motion_score | 活动强度分数 |
| state | Active / Resting / Unknown |
| battery_v | 电池电压 |
| note | 人工备注 |

## 9. 第一周开工计划

| Day | 任务 | 成功标准 |
|---:|---|---|
| 1 | 确认 ESP32 Feather V2 可烧录，OLED 可显示文字 | OLED 显示 hello 和板子状态 |
| 2 | 接 IMU，跑 I2C scan | 能识别 OLED 和 IMU 地址 |
| 3 | 读取 IMU 数据并输出串口 CSV | 静止/移动时数据变化合理 |
| 4 | ESP32 连接家里 Wi-Fi，显示 IP | 电脑浏览器能访问设备 |
| 5 | dashboard 显示实时 motion score | 移动模块时曲线明显变化 |
| 6 | 电池供电测试 30-60 分钟 | 不插 USB 也能稳定运行 |
| 7 | Delta 5-10 分钟佩戴舒适性测试 | 无抗拒、无啃咬、无压迫、数据可记录 |

第一周不需要追求漂亮算法。重点是把硬件、无线、dashboard、CSV 和佩戴安全打通。

## 10. 第一阶段实验 Protocol

实验 1 - 桌面静止噪声：

| 条件 | 记录 | 目的 |
|---|---|---|
| 模块放桌上 10 分钟 | CSV、环境备注 | 确认静止 motion score 噪声底 |

实验 2 - 手持运动：

| 条件 | 记录 | 目的 |
|---|---|---|
| 人手拿起、旋转、轻晃、放下 | CSV、动作时间备注 | 确认 active/resting 阈值可分离 |

实验 3 - 项圈空载：

| 条件 | 记录 | 目的 |
|---|---|---|
| 模块固定在项圈上，不戴狗 | CSV、视频/照片 | 检查晃动、线材、固定方式 |

实验 4 - Delta 短佩戴：

| 条件 | 记录 | 目的 |
|---|---|---|
| 5-10 分钟，有人观察 | CSV、视频、人工备注 | 检查舒适、安全、是否啃咬 |

实验 5 - Delta 室内活动/休息：

| 条件 | 记录 | 目的 |
|---|---|---|
| 30-60 分钟，包含走动、趴下、休息 | CSV、人工行为备注 | 验证活动/休息识别 |

实验 6 - 几小时记录：

| 条件 | 记录 | 目的 |
|---|---|---|
| 2-3 小时，有人间歇观察 | CSV、电池、舒适度备注 | 验证第一阶段目标 |

## 11. 第一阶段成功标准

| 指标 | 目标 |
|---|---|
| 舒适性 | Delta 愿意佩戴 30 分钟以上，无明显抓挠、抗拒或啃咬 |
| 安全性 | 无裸露线材，无压迫喉咙，无电池暴露 |
| 无线稳定性 | Wi-Fi dashboard 连续接收 30 分钟以上 |
| 数据完整性 | 能导出 CSV，时间戳连续，字段完整 |
| 活动区分 | 走动/玩耍与趴下/休息的 motion score 明显不同 |
| OLED 可用性 | 能显示 IP、电池、Wi-Fi 和当前状态 |
| 结构可迭代 | 能方便拆卸、充电、更换固定材料 |

第一阶段完成标准不是“准确识别睡眠医学指标”，而是“Delta 可佩戴 + 数据链路可用 + 活动/休息可分”。

## 12. 第二阶段扩展路线

当第一阶段稳定后，再进入第二阶段。

| 方向 | 触发条件 | 下一步 |
|---|---|---|
| 更小硬件 | Feather 模块太大但功能有效 | 迁移到更小 ESP32/nRF 板或自制 PCB |
| 更长续航 | Wi-Fi 续航不足 | 降采样、睡眠模式、BLE/nRF52840 |
| 呼吸趋势 | 下方贴合结构舒适稳定 | 加 piezo 或用 IMU 低频呼吸信号 |
| 心率探索 | 呼吸/静息窗口识别稳定 | BMI270/更高性能 IMU 做 BCG/SCG |
| 温度趋势 | 基础活动数据稳定 | 加 MCP9808 接触温度趋势 |
| 手机 App | dashboard 逻辑有效 | 迁移到 Web App / mobile app |
| 订阅服务 | 数据能形成长期 baseline | 每周报告、趋势提醒、历史数据 |

## 13. 文件结构

建议当前项目文件夹按以下结构推进：

| 文件夹 | 内容 |
|---|---|
| hardware/ | 接线图、BOM、结构照片、外壳草图 |
| firmware/ | ESP32 固件、IMU 驱动、Wi-Fi server |
| dashboard/ | 浏览器 dashboard 前端 |
| data/raw/ | 原始 CSV |
| data/processed/ | 分析结果、阈值实验、图表 |
| experiments/ | 每次实验记录、视频链接、Delta 行为备注 |
| docs/ | proposal、采购清单、weekly notes |

建议每次实验命名：

| 类型 | 示例 |
|---|---|
| 原始数据 | data/raw/2026-08-01_delta_short_wear_001.csv |
| 实验记录 | experiments/2026-08-01_delta_short_wear_001.md |
| 结构照片 | hardware/photos/2026-08-01_module_mount_v1.jpg |

## 14. 风险和应对

| 风险 | 影响 | 应对 |
|---|---|---|
| Delta 啃咬模块 | 电池和线材安全风险 | 线材全收纳，模块平滑，短时有人观察 |
| 下方贴合不舒服 | Delta 不愿佩戴 | 降低贴合压力，换侧面位置或更软材料 |
| 长毛导致信号弱 | 后续呼吸/心率困难 | 第一阶段只做活动/休息，后续再优化贴合 |
| Feather 模块偏大 | 吊牌大小目标难达成 | 第一阶段接受略大，第二阶段小型化 |
| Wi-Fi 续航短 | 几小时实验受限 | 先接受手动充电，后续 BLE/低功耗 |
| dashboard 丢数据 | CSV 不完整 | 降采样、浏览器端缓存，必要时加 microSD |
| 算法误判休息 | 睡眠记录不可信 | 先输出 Resting/Active/Unknown，不急着叫 Sleep |
| 过早加太多传感器 | 项目复杂度失控 | 第一阶段只装 IMU，接口预留 |

## 15. 后续产品化方向

如果第一阶段成功，长期产品可以走硬件 + App + 订阅路线。但第一代商业化产品不应从 GPS/cellular 开始，而应从健康趋势和活动/休息 baseline 开始。

长期产品愿景：

| 层级 | 内容 |
|---|---|
| 硬件 | 轻量项圈下方模块，BLE，低功耗，IMU + 温度 + 可选 piezo |
| App | 今日状态、休息趋势、活动趋势、佩戴质量 |
| 订阅 | 长期 baseline、每周报告、异常趋势提醒、数据导出 |
| 扩展 | 呼吸趋势、静息心率趋势、老年犬健康观察 |

产品定位仍应保持克制：

> 不做疾病诊断，先做 Delta 和普通家庭真正愿意长期使用的健康趋势记录工具。

## 16. 参考来源

- Adafruit ESP32 Feather V2: https://learn.adafruit.com/adafruit-esp32-feather-v2
- Adafruit OLED FeatherWing: https://learn.adafruit.com/adafruit-oled-featherwing/overview
- Adafruit LSM6DSOX 6-DoF IMU: https://www.adafruit.com/product/4438
- Adafruit 500 mAh LiPo Battery: https://www.adafruit.com/product/1578
- Adafruit STEMMA QT / Qwiic Cables: https://www.adafruit.com/category/619
- SparkFun BMI270 Qwiic Hookup Guide: https://docs.sparkfun.com/SparkFun_Qwiic_6DoF_BMI270/single_page/

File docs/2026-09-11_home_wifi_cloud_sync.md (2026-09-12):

# 家庭 Wi-Fi 自动同步 — 2026-09-11

## 使用方式

完整历史网址（固定）：https://delta-walk-jz-20260911.yesmora.chatgpt.site

网站仅所有者可访问；手机用同一 ChatGPT 账号登录即可，无需连接设备热点。

1. **出门**：两种触发，满足任一即开始一段新记录（约 20 Hz，带 NTP 日历时间）。
   - 连不上已保存的家里 Wi-Fi 约 10 秒；
   - 或仍在家里 Wi-Fi 范围内，但持续活动约 30 秒（中间停顿不超过 3 秒）。设备只在外出时佩戴，且住处 Wi-Fi 可能覆盖到楼下，所以「戴上并开始动」也算出门。
2. **回家**：重新稳定连上家里 Wi-Fi 15 秒后自动结束；如果整趟都没离开过 Wi-Fi，则在**静止 5 分钟**后自动结束。随后校时并按「最新一段优先」上传所有网站尚未确认的记录。
3. **看数据**：打开上面的网址，查看每段的活动曲线、采样间隙、静止／走路／跑动的时间预算和活动指数，下载完整 CSV 或原始二进制。设备本地 `/records` 页面也显示同步状态和网址。

补充行为（2026-09-11 Claude 版本）：

- 开机后先等 30 秒让家里 Wi-Fi 连上，所以在家开机不再产生一段短的「启动记录」；在外开机则 30 秒后开始记录。
- 在家 Wi-Fi 短暂掉线（少于 10 秒）不会开始新记录。
- 外出时在 `/records` 手动「停止并保存」会被尊重，直到下次回家才恢复自动记录（方便停止后下载或关机）。
- 手动开始的记录不受静止规则影响，完全由用户停止；任何一段记录在家结束后的 2 分钟内不会被运动再次触发。
- 记录头里保存触发原因（`w` 离开 Wi-Fi、`m` 持续运动、`u` 手动），写在原有的保留字节里，网站与旧解码器都不受影响。
- 在家时手动「开始新记录」不会被打断，停止后再上传。
- 设备必须保持开机直到网站显示最新记录；设备端 `/records` 中每段显示「已上传网站 / 待回家上传」。
- 未通过 USB 配置网站凭据的设备保持原行为：开机即记录，不上传。

## 存储策略

板上记录分区 4 MiB（约 2 小时）。经网站用 SHA-256 确认完整接收的记录（`.ack`）在以下情况按「最旧优先」从设备删除：

- 在家同步完成后、或每次出门开始记录前，剩余空间不足约 1 小时录制（2.3 MB）时；
- 长时间外出途中剩余空间低于 512 KiB 时，补删到约 1 MiB。

未确认的记录、正在记录的文件永远不会被自动删除；如果全部是未上传数据，存储满后仍然停止记录、不覆盖。

## 实现

- 固件：`firmware/imu_raw_stream/src/cloud_sync.{h,cpp}`；本地状态接口 `GET /api/cloud`，串口 `Q` 打印同一 JSON，`U<url>|<bypass>|<token>` 通过 USB 写入凭据（独立 NVS 命名空间 `delta-cloud`，不回显）。
- 保留原分区表、电池日志和 v1 记录格式；刷写为常规上传，不擦除数据分区。
- TLS 必须验证证书：内置 GTS Root R4（当前网站所用）以及 GTS Root R1、ISRG Root X1/X2，以防托管方更换 CA。
- 16 KiB 分块上传，按 `id + SHA-256` 定位；中断后从服务器已有的第一个缺失块继续；空 POST 显式发送 `Content-Length: 0`。
- 服务器校验整文件 SHA-256、文件头、逐条 CRC 和时间顺序后才发布并回复确认；设备只在收到确认后写 `.ack`。
- 采样路径不再每次写入都遍历文件系统统计剩余空间：改为缓存估计值，空间充足时 30 秒、接近保留区时 5 秒刷新一次，真实写入失败仍会停止记录。
- 上传复用同一个 TLS 连接（每批握手一次），离家、空闲和失败时主动关闭；被网站关掉的空闲连接会自动重握手重试一次。
- 失败处理：网络/5xx 标记 `.retry`，让其他记录先传，约 1 分钟后重试；400/413/422（网站拒收）标记 `.reject` 不再反复上传，每次重启重试一次；401/403/重定向视为凭据问题，5 分钟后重试。
- 网站分析：`site/lib/gait.ts` 在每次上传时按 4 秒窗口、2 秒步进算一次 MAD 与 0.5–5 Hz 主频，给出静止／走／跑时间预算和相对活动指数（毫 g），随记录一起存储并显示在页面上；与仓库里的 `experiments/gait_analysis.py` 是同一套算法，在台面数据上两者结果一致。活动指数不是卡路里，阈值尚未在佩戴的狗身上标定，页面上已注明。
- 网站：`site/`（独立的 Sites 源仓库，父仓库忽略此目录；`.openai/hosting.json` 保存已有 Site ID，需要在 Codex/ChatGPT Sites 中部署，Claude 会话无法部署）。R2 持久保存；设备令牌不能调用查看接口。

## 工程资料

- 设备整片备份与凭据位于忽略目录 `data/raw/cloud_sync_20260911/`（`before_flash.bin`、`secrets.config.json`）。凭据含密钥，不可提交或公开。
- Mac 端一键脚本：`bash experiments/cloud_sync_mac.sh probe|build|flash|validate|all`，日志写入同一忽略目录。
- 实机验证脚本：`experiments/validate_cloud_sync.py`（关 Wi-Fi 模拟外出 → 自动结束 → 局域网下载 → 轮询网站确认同一 SHA-256）。

## 边界

- 离家记录是约 20 Hz 目标采样，存在闪存写入造成的时间间隙（时间戳如实保留）；实测见下方基线。
- 运动触发会丢掉开头约 30 秒：没有预缓冲。如果要补上，可以用板上 2 MiB PSRAM 做一段环形缓冲，在触发时补写进文件。
- 在家被拿起、搬动超过 30 秒也可能触发一段记录，静止 5 分钟后自动结束并上传：是噪声，但不会丢数据。
- 静止 5 分钟的结束规则只针对运动触发的记录；离开 Wi-Fi 期间即使长时间静止也继续记录，狗中途休息不会被切成两段。
- 在外开机且从未联网时没有日历时间，网站不把接收时间当作开始时间。
- 外出时设备热点 `Delta-Collar` 仍开启并每 15 秒尝试重连家里 Wi-Fi，会增加耗电；一小时续航测试仍未做。
- Sites 访问令牌若过期，设备会显示认证错误并每 5 分钟重试，需要重新授权并用 `validate` 重新写入。
- 正式主机已确认为 `delta-walk-jz-20260911.yesmora.chatgpt.site`；使用设备凭据请求状态接口得到 200，无跳转。已更新本地 USB 配置中的网址。
- 采样间隙的原因已定位并修复：间隙约每 1.2 秒一次、中位 317 ms，与每秒一次的落盘同步一致，而非 Wi-Fi 重连（无 15 秒周期）；每次落盘都会调用遍历整个文件系统的剩余空间统计，分区越满越慢。改为缓存估计值后实测恢复到 19.4 Hz。剩下 3% 左右的未覆盖时间来自落盘本身，暂不处理。
- 上传速度已定位并解决。排查过程：从同一家庭网络的 Mac 测同一接口是新建连接 1,009 ms／复用 879 ms，说明约 3.3 秒耗在板子侧；先怀疑 station modem sleep，实测无效果（4.43 秒，且首个请求失败）已撤销；加上每请求日志后看到 `reused=0` 而网站回的是 `conn=keep-alive`，于是查这版 Arduino 核心的 `HTTPClient` 源码，发现 `end()` 保留 socket 但不清空内部 client 指针，随后对象析构时无条件 `stop()`，把刚保留的连接关掉了。改为常驻的 client 与 HTTPClient 成员后实测：新建连接 3,959／4,303 ms，**复用连接 1,012／1,031 ms**，与 Mac 持平，ESP32 的 TLS 握手（约 3 秒）每批只做一次。按此推算一小时记录（约 1.73 MB、109 个请求）上传从约 7.8 分钟降到约 1.9 分钟。
- 网站端分析的阈值改动需要重新部署一次网站；离线脚本可以随时改，两边的默认值要保持一致。
- 大文件在网站端一次性组装、解码：已用最大的一段（1.75 MiB／73,119 条，约 71 分钟）实测通过，详情接口 1.53 秒、CSV 导出 1.16 秒（10.8 MB、73,119 行）、原始文件下载 200。一小时散步正好是这个量级，暂不需要分片。
- 网站导出的 CSV 使用完整浮点精度（出现 `-0.35000000000000003` 这样的值），比设备端 `%.4f` 的导出大约大 50%。属于可改进项，需要改 `site/lib/motion.ts` 并在 Codex 中部署。
- 真实断电尾部恢复、真实出门佩戴仍需单独测试。

## 网站侧核对（2026-09-11 登录后实测）

| 检查 | 结果 |
|---|---|
| 记录总数 | 17 段、2.50 MB，包含设备已本地清理的旧记录——网站是完整历史 |
| 列表接口 | 200，409 ms；设备心跳在线（`mode=home`，电池 4.202 V） |
| 最大一段（73,119 条） | 详情 1.53 秒、CSV 1.16 秒（73,119 行，与样本数一致）、原始文件 200 |
| 最新一段（1,543 条） | CSV 472 ms、1,543 行；网页显示未覆盖 2.8 秒，与设备端 3.1% 吻合 |
| 旧固件那段的间隙 | 19.6% 未覆盖，与修复前的表现一致；修复后的两段为 3.1%／3.7% |

## 验证

- 固件编译与原有 72,000 条编码／解码测试通过（上一版）。
- 网站类型检查、构建、授权拒绝、分块续传、重复提交、CSV／二进制下载、CRC 损坏拒绝通过（本地合成数据，未上传到生产网站）。
- 修订版：新 C++ 在 gnu++11/gnu++17 下以 Arduino 桩头文件做类型检查通过；主机模拟验证了「只删已确认、最旧优先、达到目标即停、不删未确认或正在记录的文件、最新一段优先上传、`.retry`/`.reject` 规则」。`/records` 页面原有 Playwright 测试通过，新增同步面板在 390 px 宽度无横向溢出。
- 可复现检查：`sh firmware/imu_raw_stream/tests/cloud_sync_sim/run.sh`、`node firmware/imu_raw_stream/tests/records_cloud_panel_test.cjs`。
- **实机通过（2026-09-11 晚）**：常规刷写保留数据分区；USB 写入凭据后关闭 Wi-Fi 模拟外出 70 秒，设备自动开始记录 `e1c527b1`（1,071 条、25,736 字节），恢复 Wi-Fi 后自动结束、自动上传，网站以相同 SHA-256 `bdeb8523…` 确认完整接收。同一轮还实测到断点续传（1.75 MiB 的旧记录从第 65,536 字节继续）和自动清理（删除已确认的 `20cd0468`）。三次运行的串口日志中没有 `ERROR`、`cloud_http`、`cloud_redirect` 或读取失败。
- 实机发现并修复：跨 HTTPS 请求保留文件描述符会导致之后的 `seek` 失败；改为每块重新打开文件并定位，失败时打印 `STATUS,cloud_read_failed,...`。
- 实机运行的统一分析：`python3 experiments/analyze_cloud_sync_run.py data/raw/cloud_sync_20260911/<运行目录>`（输出采样覆盖率与主循环阻塞时间）。
- 一分钟的网络计时探测：`bash experiments/cloud_sync_mac.sh cloudtest`（串口 `T`，只读接口，打印 `STATUS,cloud_timing,...`）。
- **两项性能改动已实机复测通过（2026-09-11 21:53 与 21:56 两次运行，均通过）**：采样从 15.22 Hz 回到 19.46／19.43 Hz，未覆盖时间从 28.5% 降到 3.1%／3.7%，最大间隔从 760 ms 降到 366／325 ms。上传方面，复用连接后首个请求（含握手）8.0–9.7 秒，随后每个请求约 4.2 秒；剩下的时间不在握手上，需确认是否为网站端响应时间（见 `experiments/measure_cloud_latency.py`）。
- 两次复测之间，板子把此前 10 段共 2.30 MiB 积压全部上传完毕，并按策略删除了已确认的旧记录（含 1.75 MiB 的 `82ce2b54`）；复测开始时待上传均为 0。

## 实机实测数据（2026-09-11）

| 项目 | 改动前基线 | 改动后（两次复测） |
|---|---|---|
| 外出采样 | 15.22 Hz，28.5% 未覆盖，最大间隔 760 ms | **19.46／19.43 Hz，3.1%／3.7% 未覆盖，最大间隔 366／325 ms** |
| 大于 100 ms 的间隔 | 61 段／70 秒 | 13 段／79 秒、16 段／76 秒 |
| 每个上传请求阻塞 | 中位 4.8 秒 | 首个（含握手）约 4.0 秒，之后 **1.01 秒**（同一接口在 Mac 上约 0.9 秒） |
| 一次外出记录 | 1,071 条 | 1,543 条、1,470 条，网站均以相同 SHA-256 确认 |

| 项目 | 实测 |
|---|---|
| 外出记录（基线明细） | 1,071 条，70.4 秒，平均 15.22 Hz；间隔中位数 50 ms，最大 760 ms；大于 100 ms 的间隔 61 段合计 20.0 秒（28.5% 未覆盖） |
| 回家自动结束 | 恢复 Wi-Fi 后约 26 秒（连接时间加 15 秒稳定判定） |
| 上传速度 | 每次 HTTPS 请求阻塞主循环中位数 4.8 秒、p90 10.3 秒；16 KiB 一块，约 3 KB/s |
| 板上积压 | 10 段共 2.30 MiB（含旧固件遗留的 1.75 MiB 与 526 KiB 中断记录），在家自动陆续上传 |
| 电池电压 | 4.202 V（USB 供电，未做续航测试） |

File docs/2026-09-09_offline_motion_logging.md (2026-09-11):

# 离线运动记录开发交接 — 2026-09-09

日终总览与图片入口：[今日报告](2026-09-09_daily_report.md)。

用户已报告 v0.4 打印、组装完成，提供了合盖、交叉魔术贴和外置开关的照片。
当前方向是探索胸背式遛狗活动记录，但用户明确要求**先处理数据记录和查看，暂不推进佩戴或上狗测试**。
本轮补齐软件记录链路，不将装配完成视为续航、佩戴或运动识别已经通过验证。

**USB 连接后的更新：** 已完成整片备份、刷机和首次两分钟实机测试，验证真正关闭 Wi-Fi 后持续记录、完整下载和重启保持。
主记录 `f35506a5` 共 2,279 条，实测约 18.97 Hz；同步写入有采样间隔抖动。
详见 [实机测试报告](../experiments/offline_usb_bench_2026-09-09.md)。一小时电池与直接断电验证仍待完成。

## 本轮实现

- Feather 启动、IMU 和存储初始化成功后自动新建记录；脱离家庭 Wi-Fi 或关闭网页后继续写入。
- 保留原有分区，新增上半区 4 MiB 运动数据存储。20 Hz 下，一小时文件为 1,728,032 字节，另计文件系统开销。
- 保存原始六轴数据、时间、传感器温度、电压和简单活动分数/状态；约每秒批量同步，停止时保存尾批。
- 空间不足停止且不覆盖历史；异常重启保留未正常结束文件；校验损坏并提供原始文件恢复工具。
- `/records` 中文手机页面可停止/开始、列出历史、看整段曲线、下载完整 CSV 或二进制、确认后单条删除。
- 历史传输在停止采样后进行；网页原来的约 45 秒实时图继续保留，其按钮明确区分于完整历史。
- 手机与设备可以通过设备热点直接连接，不要求互联网。云端网站上传和蓝牙传输未实现；实机测试增加串口 `O` 关闭 Wi-Fi、`W` 恢复，用于验证真正无无线连接的记录。

## 验证及边界

- PlatformIO / Espressif32 7.0.1 / Arduino 2.0.17 编译通过，程序仍放得进原来的应用分区。
- 72,000 条合成样本通过实际 C++ 编码/缓冲后由独立 Python 工具读取，记录数、时间、符号与单位正确。
- 校验位损坏、截断尾部、重复时间戳、缓冲写失败、部分批次停止、旧分区地址/容量保持等主机检查通过。
- 浏览器模拟设备 API，手机/桌面布局及完整一小时曲线、72,000 行下载、断连、异常记录与删除取消流程通过。
- 下载同时核对服务端记录条数；截断传输报错，不显示为完整成功。
- 软件检查阶段用户选择稍后连接 USB；随后用户已接入并授权继续，现已备份、刷机和执行短测。
- 设备双 LittleFS 挂载、Wi-Fi 关闭后持续保存、CSV 与二进制逐条对比、正常停止文件在重启后不变、未停止文件重启后标记并恢复均通过。
- 原有 560 条电池日志逐行保留。当前 Wi-Fi 恢复、记录停止，所有测试文件仍保留在板上。
- 主机和实机结果分别记录；EN 重启不作为实际断电验证，USB 短测不作为一小时电池续航验证。

## 继续工作

1. 在手机浏览器查看设备 `/records`，主测试编号 `f35506a5`。设备已经停止记录；可手动开始新记录，或重新开机自动开始。
2. 继续一小时桌面电池记录，检查续航、间隙、存储实际占用及完整下载。
3. 如需更严格的固定采样率，先解耦采样与闪存写入，再比较间隔分布。
4. 单独验证直接断电恢复及写满行为，并验证离开家庭网络时热点自动恢复。
5. 用真实记录调整活动判定和报告；不将简单阈值解释为走/跑识别、步数、距离或热量。

操作、数据格式与测试命令见 [固件说明](../firmware/imu_raw_stream/README.md)。
原装配资料继续见 [Stage 1B 交接](2026-09-09_stage1b_handoff.md)，其中较早的“待打印/组装”状态由本页的用户确认更新。

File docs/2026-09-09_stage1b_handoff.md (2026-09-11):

# Stage 1B 工作交接 — 2026-09-09

**后续更新：** 用户已确认 v0.4 打印并组装完成。当前优先离线记录和手机查看，暂不推进佩戴/上狗。
见 [离线运动记录交接](2026-09-09_offline_motion_logging.md)；下文保留此前打印文件交付时的状态快照。

当前进度：**小外壳 v0.4 已完成设计和打印文件交付，用户准备打印；下一步收集打印完成及断电试装反馈。**
目前尚未收到 v0.4 底盒、盖子打印完成或实物配合通过的确认。

## 从这里继续

| 用途 | 当前入口 |
|---|---|
| 一次拿齐打印文件 | [v0.4 试装打印包 ZIP](../hardware/enclosure/print_packages/delta_collar_v0_4_fit_print_20260909.zip) |
| 底盒、盖子尺寸和朝向 | [v0.4 使用说明](../hardware/enclosure/v0_4/README.md) |
| 对照摆放、绕线 | [高清静态图](../hardware/enclosure/v0_4/placement_routing.png)、[交互图 HTML](../hardware/enclosure/v0_4/placement_routing.html)（下载后浏览器打开） |
| CAD 尺寸修改入口 | [design_inputs.json](../hardware/enclosure/v0_4/design_inputs.json) |
| 本次 USB 测试证据 | [两分钟串口观测报告](../experiments/usb_slide_fit_2min_2026-09-08.md) |
| 完整尺寸来源与更正 | [卡尺测量记录](2026-09-08_stage1b_caliper_measurements.md) |
| 托盘实物与理线迭代 | [9 月 9 日试装记录](2026-09-09_stage1b_tray_fit_and_cable_routing.md) |

## 已完成与当前状态

| 项目 | 状态与证据 |
|---|---|
| 原 Stage 1A 硬件和大盒台架 | 已完成 I2C/IMU、无线网页、大盒 15 分钟 USB、15 分钟电池、4 分钟手持动作测试；见 [原台架记录](2026-08-14_stage1_enclosure_bench_and_calibration.md) |
| GitHub 同步 | 本轮起点为 main 的 `7b54d0d`，后续测量、测试与 CAD 成果在本轮整理提交 |
| 游标卡尺与关键实测 | 已到货，板组、电池、安装孔、开关和插头相关数据已记录 |
| IMU 背面装配 | 用户从侧面滑入排针塑料座之间，机械卡持牢固；没有胶或新增垫层，组合高度仍为 16.36 mm |
| 当前装配短时 USB | 约 120.5 秒，2,370 条有效样本，19.981 Hz；无固件错误、首次启动后无时间戳回退。用户确认电池断开、无异常发热/异味/明显弯曲 |
| v0.3 低托盘 | 用户已打印，确认 Feather＋IMU 与电池可并排放下并有余量，照片已归档 |
| 27 mm 理线座 | 根据用户约 30 mm 的实测空间，由 32 mm 缩至 27 mm；用户此前表示打印中，尚未反馈最终绕线效果 |
| v0.4 带盖底盒 | 四柱、USB 开口、开关线槽、独立盖子已生成；网格与名义干涉检查通过，实物打印/试装待反馈 |
| 放置与绕线图 | 已交付静态图和可切换线路的交互图，作为试放方案；未按实测线长完成弯曲仿真 |
| 打印包 | 已交付并核对压缩包内容与 STL 哈希；用户确认准备开始打印，助手没有切片或发起打印 |

## 当前尺寸基准

单位均为 mm；实测尺寸与设计留量分开保存。只在后续试装发现变化时修订相关值。

| 项目 | 实测/确认值 |
|---|---|
| Feather PCB 长 × 宽 | 51.57 × 22.80 |
| Feather 含 USB 金属接口长度 | 52.05，接口超出 PCB 0.48 |
| Feather 含排针总高；当前 Feather＋IMU 总高 | 都为 16.36；IMU 嵌在排针间，不额外叠加厚度 |
| 上/下突出量 | 1.18 / 9.10，保留用户原始方向定义 |
| IMU 单体 | 25.51 × 17.82 × 4.71 |
| 两排金属针内侧距离 | 19.59；不包括塑料座占位，不能当作可安装净宽 |
| 左两孔/右两孔直径 | 2.45 / 2.52；左有金属圈，右无金属圈 |
| 右孔支撑通道 | 用户已确认 IMU 不遮挡，可从下方放柱；柱径和四孔对位仍需实际试装 |
| 电池 | 35.90 × 32.25 × 4.80，宽度包含沿边电线 |
| 外置开关 | 45.05 × 15.89 × 15.19，包含 OFF 状态按钮 |
| 实际 USB 线插头金属外壳 | 宽 8.95 × 高 3.30 |
| 通往开关的线束合计自然宽 × 厚 | 3.32 × 1.59；实际试放时将需要出盒的全部线一起放入槽内 |
| Feather 白色电池插头硬塑料超出板边 | 1.06，不含软线；当前位置到内壁的名义余量约 0.94 |

孔边距是从**孔内缘**到板边测得。元件面朝上、USB 在左时，以 PCB 左上角为原点，X 向右、Y 向下，推算孔中心为：

- 左上 `(2.855, 2.565)`，左下 `(2.855, 20.235)`。
- 右上 `(48.890, 2.600)`，右下 `(48.890, 20.200)`。

坐标小数位来自计算，不等于卡尺精度；四柱对位尚未经打印实物验证。旧文档中的 7.2/4.6 mm 不作为裸 PCB 板厚。

## 当前打印与装配方案

- **底盒：** 65.25 × 65.25 × 21.36，底厚 2.0、壁厚 1.6，四柱已合并在实体中。
- **盖子 STL：** 69.05 × 69.05 × 15.57，已按外侧大平面贴打印板放置；高度包含伸入盒内的出线挡片。合盖后总外尺寸为 69.05 × 69.05 × 22.96。
- **支撑柱：** 顶面距内底面 10.10，让下排针离底约 1.00；柱内为直径 1.60、深 6.00 的 M2 试配导孔。采购记录没有确认 M2 螺钉，正式锁固需匹配螺钉及长度；可先无螺钉对孔试放。
- **理线座：** 独立 20 × 27 × 9 配件，继续复用；双面胶和线圈高度未计入 9 mm。原 32 mm 文件保留为历史，不作为当前打印文件。
- **USB：** 开口净宽 10.15，垂直留量较大；核对实际插入和合盖插拔。
- **开关：** 保持盒外，通过右侧 4.52 mm 宽的 U 形槽放线，盖挡片将开口限位到最大 3.39 mm 高；此处不作为完整防拉扯固定。
- **盖子：** 外套式试装盖，单侧设计间隙 0.30；没有锁扣，实际松紧与佩戴保持力尚未验证。

俯视摆放时 USB 在左、Feather 在上、电池在左下、理线座在右下。IMU 保持背面现位，四色线先留松弯；较长的电源线沿两柱外侧整理，外置开关的外部余线用现有魔术贴收拢。Feather 电池插头软线抬起后向板上回弯，不塞入约 0.94 mm 的边缝；该弯和 IMU 线圈都需要检查合盖高度。

用户的既定装配偏好：保留当前很紧的 IMU 机械卡持，不为补胶强行拔出。已有泡棉双面胶可用于理线座底面；本轮没有要求新购绝缘材料。短时 USB 正常只证明该观察窗口的基本功能，板间接触与运动保持情况仍需后续实际核对。

## 下一次工作按此顺序进行

1. 先确认 v0.4 底盒、盖子和 27 mm 理线座是否打印完成，收集打印失败、毛刺或尺寸偏差反馈。
2. 断电轻放板组，检查四孔对齐、四柱支撑平稳、排针不顶底；电池平放并能取出。
3. 参照绕线图试放，所有开关线一起入槽；USB 线电脑端断开时先试板端插拔。轻合盖检查挡片不夹线、JST 回弯和 IMU 松弯不顶盖。
4. 记录俯视和侧视照片、干涉部位及必要补测，只修改受影响参数后再出修订版。
5. 配齐并试配锁固件，完成电池保持、外置开关固定、出口防拉扯和项圈固定结构。
6. 装配确认后继续外壳内 USB、电池及动作验证；1 小时电池运行、全程数据采集和汇总图仍待完成。Delta 佩戴测试尚未开展。

## 可复现文件与数据范围

- v0.3 托盘与理线座均包含 STL、SCAD、生成脚本及验证 JSON。
- v0.4 使用 `design_inputs.json` 和 `generate_enclosure.py` 生成实体；`assembly.scad` 只是导入 STL 的装配查看器。
- CAD 生成环境为 Python 3.12.3，库版本见 [依赖清单](../hardware/enclosure/requirements.txt) 与各验证 JSON。绘图字体路径目前使用 macOS 系统 Arial；换到其他系统时调整字体路径。
- 交互绕线图同时归档可编辑的 `.fragment.html` 源文件和可直接打开的独立 `.html`，在 GitHub 页面下载后打开即可切换线路。
- 当前两分钟观测报告包含统计和上下文。原始 CSV/LOG/JSON 按 `.gitignore` 留在本地 `data/raw/usb_slide_fit_20260908_155405.*`；新克隆仓库不会自动获得这些原始文件。
- 本轮没有修改固件、刷机或执行新的通电测试。

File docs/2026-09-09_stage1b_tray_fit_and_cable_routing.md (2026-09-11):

# Stage 1B：托盘实物试装与理线需求 — 2026-09-09

后续状态：用户已确认 v0.4 打印和组装完成，离线记录固件已刷入并通过 USB 短测。见 [日终报告与图片](2026-09-09_daily_report.md)；下文保留此前试装和设计过程。

## 已确认的进展

用户已打印 v0.3 试装托盘，并确认 Feather＋IMU 组合与电池可以并排放下，仍有空余空间。
这确认了初步平面布局；固定柱位置、带盖后的高度和完整装配还未验证。

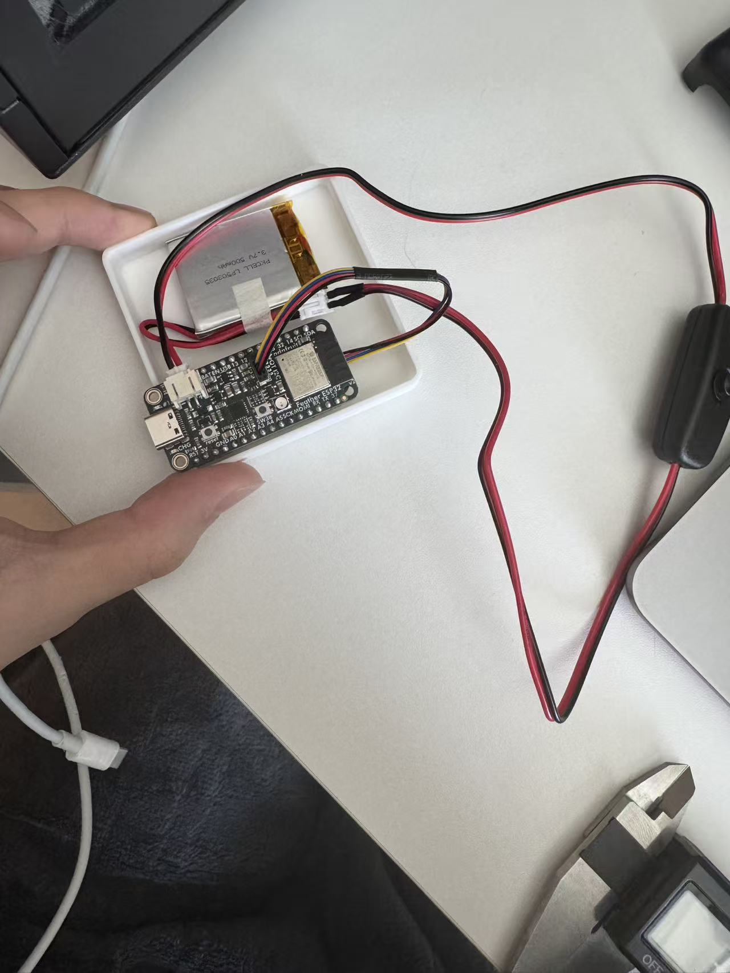
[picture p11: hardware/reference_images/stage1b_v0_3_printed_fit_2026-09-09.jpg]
v0.3 实物试装


照片中开关保持外置。红黑开关线较长，四色 IMU 线也有一段余量；用户提出加入绕线柱。
本次没有新增通电测试，也未从照片推算新的精确尺寸。

## 已准备的改动：双柱理线座

当前文件：[delta_collar_v0_3_cable_guide_27mm.stl](../hardware/enclosure/delta_collar_v0_3_cable_guide_27mm.stl)。

用户随后实测可用长边约 30 mm，要求尽量做成 27 mm。已将原 32 mm 版本修订为 27 mm，并同步调整柱径和柱距；当前以文件名带 `27mm` 的版本为准。

这是可追加到已有托盘的小配件，用来先验证理线位置，后续可把结构合并进完整底盒。
已打印托盘的外尺寸继续保留为 65.25 × 65.25 mm。

| 项目 | 设计尺寸 |
|---|---:|
| 理线座整体尺寸（X × Y × Z） | 20 × 27 × 9 mm |
| 平底厚度 | 1.2 mm |
| 两柱中心距 | 14 mm |
| 柱身直径 | 10 mm |
| 顶部挡边直径 | 12 mm |
| 两挡边之间净距 | 2 mm |
| 柱身可绕线高度 | 6 mm |

上述是本轮设计初值，不是电线厂商给出的最小弯曲半径或已验证收线容量。
9 mm 总高不包含双面胶厚度和电线绕好后的外包络。
圆柱顶部采用斜面挡边和倒角，底板四角为圆角。

理线座模型及建议位置

图中的建议位置是原模型电池旁的空位。按既定摆放坐标，理线座底板距离电池占地约 2.5 mm，距离板组占地约 1.6 mm；这些是模型计算间隙，实际线材尚需试放确认。不要把理线座或绕出的线压在电池上。

## 现在如何使用

1. 在 Bambu Studio 用文件名带 `27mm` 的 STL 替换旧理线座，缩放保持 100%，确认尺寸为 20 × 27 × 9 mm。不要对旧 32 mm 版整体等比例缩放，以免同时缩小高度与壁厚。平底朝下、两柱朝上，沿用已有材料配置；先切片检查，再自行打印。模型的挡边下方是 45° 斜面，未替用户执行切片或打印。
2. 冷却并清理毛刺后，先断电放入托盘中的空位，不急着粘。
3. 让盒内余线围绕两柱外侧形成松的椭圆圈，不在两柱中间的窄缝里挤线，不把线绷紧。接头附近保留自然弯曲与插拔松量；遇到明显回弹或需要压线才能放下时，调整布局。
4. 理线合适后，用已有泡棉双面胶贴在理线座底面，固定到托盘底部。此胶用于理线座，不要求拆开已经卡住的 IMU。
5. 外置开关那一侧过长的线段可以留在盒外，后续用已有魔术贴固定在项圈／模块外侧。理线柱整理盒内余线，不能代替外部线材出口的防拉扯固定，也不保证能收纳全部开关线。
6. 线材摆好后提供俯视和侧面照片，检查电池可取出、插头不受拉、余线没有高过计划的盖内空间，再确定完整底盒、固定柱、出线口及盖子。

## 文件核对与后续范围

- STL 由实体布尔运算生成，并重新读入检查：单个实体，1,552 个三角面，表面闭合、面朝向一致、无退化三角面、外尺寸符合预期。
- 已查看由实际导出 STL 渲染的模型预览。尚未完成切片和实物验证。
- [可编辑 SCAD](../hardware/enclosure/delta_collar_v0_3_cable_guide_27mm.scad)、[生成脚本](../hardware/enclosure/generate_v0_3_cable_guide.py)、[核对结果](../hardware/enclosure/delta_collar_v0_3_cable_guide_27mm_validation.json)均已保存。原不带 `27mm` 后缀的 32 mm 文件仅作历史记录。
- 此配件不替代完整外壳版本；后续已设计 v0.4 底盒及盖子，见下文。绕好线的实际高度仍待试放。

## 后续补测与 v0.4 带盖底盒

用户在理线座打印期间要求继续添加充电口、开关出线口及 Feather 固定桩。随后补充：

| 项目 | 用户确认值 |
|---|---|
| USB 线插头外壳宽 × 高 | 8.95 × 3.30 mm，外壳为金属 |
| Feather 右侧两个孔下方 | 能放支撑柱，IMU 无遮挡 |
| 开关线合计自然宽 × 厚 | 3.32 × 1.59 mm |
| Feather 白色电池插头硬塑料超出 PCB 长边 | 1.06 mm，不含软线 |

“高度和外壳一致”的最初描述已由明确的 3.30 mm 替代。保持当前 IMU 卡持状态，组合高度仍是 16.36 mm。

已生成 [v0.4 底盒与独立盖子](../hardware/enclosure/v0_4/README.md)：

- 底盒沿用 65.25 × 65.25 mm 外部平面，升高到 21.36 mm；底厚 2 mm，壁厚 1.6 mm。
- 四柱顶距内底面 10.1 mm，排针离底设计间隙 1 mm。柱内为 M2 试配导孔，需要合适螺钉才能锁固；采购清单尚未确认 M2 螺钉。
- USB 侧开口净宽 10.15 mm；开关侧线槽宽 4.52 mm，合盖后最大高度 3.39 mm，底角为圆角。线可以开盖放入，盖上的挡片负责限位。
- 外套盖裙单侧间隙 0.3 mm；装配后整体 69.05 × 69.05 × 22.96 mm。此配合尚未实物验证。
- 27 mm 理线座继续作为独立可复用配件，给已有打印预留位置。双面胶和绕线后的额外高度不包含在理线座模型中。

底盒/盖子 STL 重新读入验证通过：分别为单个闭合实体、朝向一致、尺寸正确；名义合盖状态无实体碰撞，USB 与线束开口保持贯通。已查看实际网格渲染图。尚未切片、打印或确认实际孔位与盖子公差。下一步按 v0.4 说明进行断电试装和固定件试配。

随后按用户要求准备了 [俯视摆放与绕线图](../hardware/enclosure/v0_4/placement_routing.png)。绘图时补核电池插头，用户测得硬塑料超出板边 1.06 mm；原板边净空 2 mm，硬塑料名义余量 0.94 mm，因此软线安排向上回弯、另核合盖高度，不把窄缝作为走线槽。未修改底盒和盖子几何。

图中保留当前 IMU 背面卡持，IMU 线留松弯；长电源线沿两柱外侧整理，开关外部余线用现有魔术贴收拢。零件平面占地按参数绘制，接头与软线曲线仅为方案示意，线长、绕线圈数和弯曲高度仍待实际试放。

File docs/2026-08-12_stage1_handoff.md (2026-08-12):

# Stage 1 Handoff - 2026-08-12

This note records the completed work and the next safe steps for the Delta collar prototype. Read this file at the start of the next working session.

## Completed Today

- Cloned and prepared the `CUJonZhao/petring` repository.
- Confirmed the Adafruit ESP32 Feather V2 is detected over USB at 115200 baud and identified it as an ESP32-PICO-V3-02 with 8 MB flash.
- Connected the Adafruit LSM6DSOX to the Feather through the STEMMA QT cable.
- Verified I2C address `0x6A` and `WHO_AM_I` value `0x6C`.
- Added and uploaded two PlatformIO firmware projects:
  - `firmware/bringup_i2c_scanner`: I2C connection check.
  - `firmware/imu_raw_stream`: IMU streaming, battery-voltage trend logging, browser dashboard, and Wi-Fi configuration.
- Completed a 10-minute static USB bench test: 12,003 valid IMU samples over 599.95 seconds, with no reset during the test.
- Completed a 10-minute battery-only bench test: 599.31 seconds, with battery-voltage trend from 3.936 V to 3.908 V. This is a short bench test, not a full-runtime test.
- Configured the ESP32 to join the apartment Wi-Fi through its local setup page. The address obtained on 2026-08-12 was `http://172.24.23.76`; it is DHCP-assigned and may change after a router or device restart.
- Verified the dashboard and `/api/latest` work over apartment Wi-Fi.
- Changed the firmware so the `Delta-Collar` recovery AP turns off after joining apartment Wi-Fi. It automatically comes back if the apartment Wi-Fi connection is unavailable.
- Measured the ESP32 module shield at about 35 C using an IR thermometer while the board was operating. The battery, JST connection, and other board areas were not noticeably warm.
- Connected the LiPo through the inline JST switch with USB attached. With the switch set to `ON`, the Feather `CHG` LED illuminated, confirming charging had started. Do not assume charging completed unless the `CHG` LED later turns off.
- Committed and pushed the above firmware, test records, and the correct enclosure-space reference image as Git commit `feb8ff6`.

## Current Hardware State

- Feather, LSM6DSOX, LiPo, inline switch, and USB were connected at the end of the session.
- The LiPo charge process was in progress, indicated by the orange `CHG` LED.
- The original 70 x 42 x 23 mm enclosure is too tight for a safe flat layout containing the Feather, LiPo, IMU, and cable. Do not force parts into it or stack/compress the LiPo.
- A larger Zulkit enclosure was ordered: 90 x 70 x 28 mm external dimensions. Verify its actual internal dimensions and lid clearance when it arrives.

## Tomorrow: Enclosure Arrival Plan

1. Before handling or arranging components, unplug USB and set the inline battery switch to `OFF`. Keep the LiPo on a non-conductive surface.
2. Inspect the new box for internal screw posts, sharp plastic, and its usable internal length, width, and height. Do not assume the advertised external dimensions equal its internal space.
3. Do a powerless dry fit first: Feather, IMU, JST switch, and cables only. Confirm the USB port, switch, and STEMMA QT cable can exit without a sharp bend or pinch.
4. Add the LiPo only after the board layout is settled. It must lie flat, remain removable for inspection, and have no contact with screw posts, PCB corners, or the lid. Do not glue, tape over, bend, puncture, or compress the battery.
5. Close the lid gently without fastening it. If any force is needed, stop and change the layout. The assembly needs visible clearance, not a press-fit.
6. With the battery switch still `OFF`, run the Feather from USB in the closed box for 15 minutes while supervised. Use the IR thermometer on the outer box near the ESP32 position. Stop for fast temperature rise, odor, discoloration, reset, or a hot connector.
7. If the enclosed USB test is normal, repeat a 15-minute supervised test on battery power with USB removed. Keep the box on a desk; do not attach it to Delta yet.
8. Only after both enclosure bench tests pass, perform the planned motion calibration: 2 minutes still, 1 minute normal hand movement, and 1 minute gentle turning/stopping. Download the Dashboard browser CSV for threshold review.
9. A first short collar-fit test must be supervised, with the enclosure mounted so it cannot shift, press into Delta, or expose any cable/battery. Do not charge while worn or while the enclosure is closed.

## Safety Limits

- Charge only while attended, on a hard non-flammable surface, with the battery not enclosed or compressed.
- Stop immediately for battery swelling, heat at the battery or JST connector, odor, discoloration, smoke, unexpected resets, or a board/enclosure temperature that rises rapidly.
- The dashboard `battery_v` reading is an approximate voltage trend, not a precise remaining-capacity indicator.
- This is an engineering prototype, not a veterinary diagnostic device.

## Resume Prompt

Use this in the next Codex task:

> Continue the Delta collar Stage 1 build from `docs/2026-08-12_stage1_handoff.md`. The larger enclosure has arrived. Guide the safe powerless dry fit first, then the enclosed USB and battery bench tests. Do not recommend wearing it on Delta until those checks pass.

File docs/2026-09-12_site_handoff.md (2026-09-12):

# 网站续接 — 2026-09-12

网站分析更新已发布成功，仍仅所有者可访问：
https://delta-walk-jz-20260911.yesmora.chatgpt.site

网站独立仓库备份：https://github.com/CUJonZhao/petring-site （private）。
本地 site/ 的 github 远端用于备份；Sites 源仓库用于发布，二者已推送同一提交。
网站提交：9d5703e2dda64589cd0b3f484a4d7aaa0ae57dc0，Sites version 2。

## 本次变更

- 上线昨晚的活动分析与室内手持阈值。
- 主指标采用同一套窗口分析的静止／走／跑时间；设备原始活动曲线独立标注。
- 区分采样间隙与分析窗口未分类时间，明确跑动阈值未标定、犬类佩戴未验证。
- 详情加载失败显示独立重试入口；列表自动刷新不会清除详情错误。
- 旧记录详情以当前重新计算的 summary 覆盖旧元数据；列表移除可能过时的行为汇总。
- 更新运动触发和存储说明。

## 验证与限制

TypeScript 类型检查、生产构建通过。本地已有测试记录页面可打开并显示新文案。
在本次评估中，用 ce940dee 原始记录重算：静止 180 秒、走 162 秒、跑 0 秒、活动指数 80 mg。
该记录原始采样间隙为 8.728 秒；窗口未分类为 2 秒，两者不是同一个指标。
Sites 返回部署 succeeded。线上登录后的记录与下载尚未复核，浏览器缺少登录会话。
未刷写设备，未进行新的实机或电池测试。

## 下一步

1. 登录网站，核对 ce940dee 的上述分析值与下载。
2. 一小时电池独立记录与回家上传验证。
3. 用户恢复佩戴测试后，用标注的胸背记录重新标定犬类静止／走／跑。

环境：当前 bundled Node 可运行项目的 scripts/run-framework.mjs build；登录 shell 没有 npm。
Sites 插件缓存路径在本次工作中发生变化，打包使用当时可用的 bundled sites/package-site.sh。
密钥和原始记录继续只保留在忽略目录，不在 GitHub 网站源码备份中。

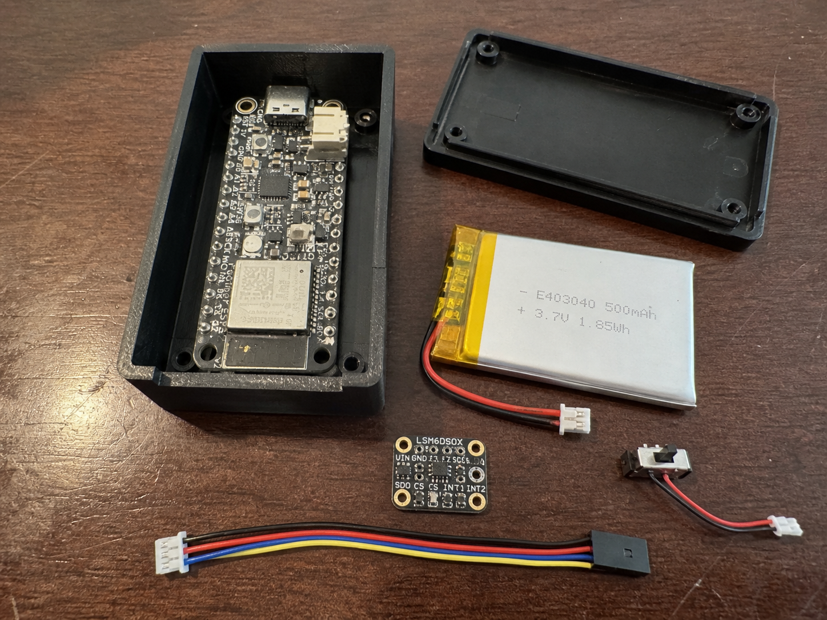
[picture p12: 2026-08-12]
hardware/reference_images/enclosure_fit_limit_reference_v2.png

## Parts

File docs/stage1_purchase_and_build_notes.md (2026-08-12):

# Stage 1 Purchase And Build Notes

Last updated: 2026-08-12

This file preserves the practical context from the planning conversation so a new Codex task can continue the project without losing the hardware and purchase decisions.

## Project Intent

- Build a real usable prototype first, not only a paper proposal.
- First user is Delta, a 4-month-old Sheltie, about 7.5 kg, long fur, willing to wear a collar, no known health issue at planning time.
- Current priority is sleep/rest and activity recording.
- First experiments should run for a few hours, then the design can be upgraded.
- The collar module must be wireless during use; no cable tethered to a computer.
- Start with a computer/browser dashboard before moving to a phone app.
- Comfort matters more than maximum sensor accuracy in Stage 1.

## Stage 1 Architecture

- Controller: existing Adafruit ESP32 Feather/HUZZAH32 V2, USB-C, LiPo JST connector, STEMMA QT connector.
- Primary sensor: Adafruit LSM6DSOX 6-DoF accelerometer/gyroscope, STEMMA QT/Qwiic.
- Power: Adafruit 3.7 V 500 mAh LiPo battery.
- Switch: JST-PH 2-pin extension cable with on/off switch between battery and Feather.
- Communication: ESP32 connects to home Wi-Fi.
- Computer side: local browser dashboard for live motion score, rest/activity status, battery/status display, and CSV saving.
- Wearable structure: small ABS project box mounted under the collar with foam padding and removable hook-and-loop straps.

## Purchased / Recommended Items

Adafruit:

- Adafruit LSM6DSOX 6 DoF Accelerometer and Gyroscope - STEMMA QT / Qwiic, PID 4438, qty 1.
- Lithium Ion Polymer Battery - 3.7 V 500 mAh, PID 1578, qty 1.
- STEMMA QT / Qwiic JST SH 4-pin Cable - 100 mm Long, PID 4210, qty 2.
- STEMMA QT / Qwiic JST SH 4-pin Cable - 50 mm Long, PID 4399, qty 1.
- JST 2-pin Extension Cable with On/Off Switch - JST PH2, PID 3064, qty 1.

Amazon:

- XHF 3:1 adhesive-lined waterproof heat shrink tubing kit, black.
- SEEKONE 350 W mini heat gun.
- 3M 1/2 inch foam double-sided mounting tape.
- Nettbe 6 inch reusable hook-and-loop cable ties.
- MYFAMIREA 1/8 inch adhesive neoprene foam padding sheets.
- HoHaing ABS project box, 2.76 x 1.65 x 0.91 inch / 70 x 42 x 23 mm.

## Existing Hardware Notes

- The ESP32 Feather/HUZZAH32 V2 has male headers soldered.
- The 128x32 Monochrome OLED FeatherWing also has male headers soldered.
- Because both boards have male headers, the OLED cannot directly stack on the Feather as-is.
- For the wearable Stage 1 build, skip the OLED to reduce height and complexity.
- The OLED can still be used later for bench debugging if connected with jumpers/breadboard or if headers are reworked.
- Existing Adafruit ADXL345 accelerometer can be used for I2C practice and as a backup/comparison sensor, but the LSM6DSOX remains the preferred Stage 1 sensor because it includes a gyroscope.

## Mechanical Notes

- The original 70 x 42 x 23 mm project box is too tight for a safe flat layout containing the ESP32 Feather, LiPo, IMU, and wiring. Do not force or stack parts inside it.
- Use the larger 90 x 70 x 28 mm external-dimension project box selected after the first dry fit. Verify its usable internal dimensions and lid clearance before assembly.
- Place adhesive foam on the box side facing Delta/collar; do not put adhesive directly on fur or skin.
- Use hook-and-loop straps around the collar/module so the assembly is removable and adjustable.
- Keep the hard strap head away from the dog-facing side.
- Avoid permanent glue on the LiPo so the battery can be inspected and replaced.

## LiPo Safety Notes

- The Adafruit 500 mAh LiPo has a JST-PH plug compatible with Adafruit Feather boards.
- It includes protection circuitry, but that does not make it risk-free.
- Charge only through a LiIon/LiPo constant-current/constant-voltage charger, such as the Feather's onboard charger via USB-C.
- Charge current should be 500 mA or less for this 500 mAh battery.
- Do not charge or test unattended.
- Do not bend, crush, puncture, short, or compress the battery.
- In the project box, make sure the battery is not pressed by screw posts, PCB corners, or the box lid.
- Adafruit LiPo polarity matches Adafruit boards; avoid random third-party LiPo packs unless polarity is verified.

## First Build Sequence

1. Confirm ESP32 Feather powers from USB-C.
2. Connect LSM6DSOX to Feather using STEMMA QT/Qwiic.
3. Run an I2C scanner to confirm the sensor appears.
4. Stream raw IMU values over serial.
5. Connect ESP32 to Wi-Fi and expose a minimal browser page or WebSocket endpoint.
6. Build a simple dashboard showing motion score and current rest/activity state.
7. Save CSV logs during short supervised tests.
8. Mount electronics in the project box without OLED for the first wearable trial.
9. Run a short non-wear bench test, then a supervised collar fit test, then a 30+ minute data test.

## Follow-Up Prompt For New Codex Tasks

When starting a new task in this folder, ask Codex:

Please read `D:\petring\README.md`, `D:\petring\docs\stage1_purchase_and_build_notes.md`, and `D:\petring\docs\canine_resting_vitals_smart_collar_proposal_v3_delta_first.md`, then continue the Delta smart collar Stage 1 build.

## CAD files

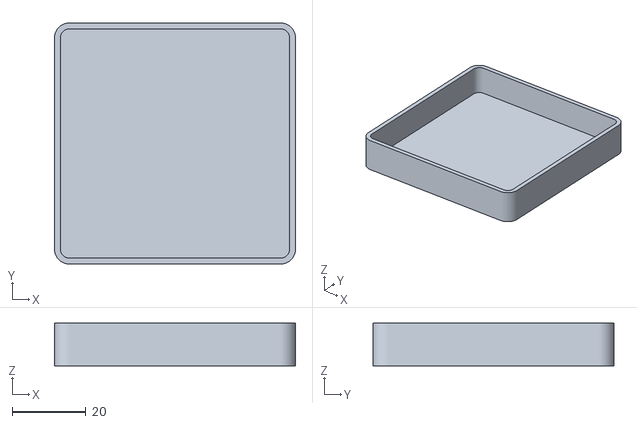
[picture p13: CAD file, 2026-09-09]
hardware/enclosure/delta_collar_enclosure_v0_3_fit_tray.stl
65.2 x 65.2 x 11.6

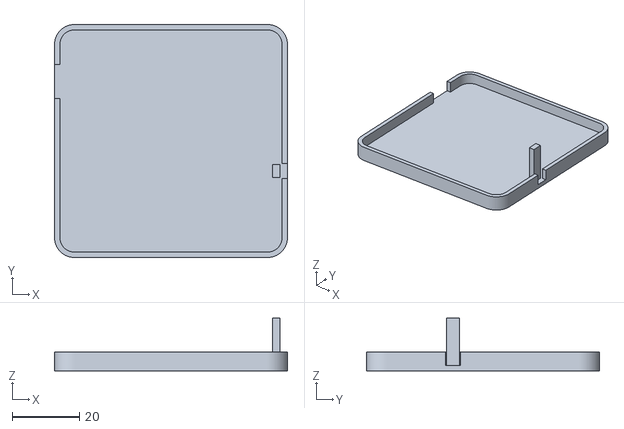
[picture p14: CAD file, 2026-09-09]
hardware/enclosure/v0_4/delta_collar_v0_4_lid.stl
69.1 x 69.1 x 15.6

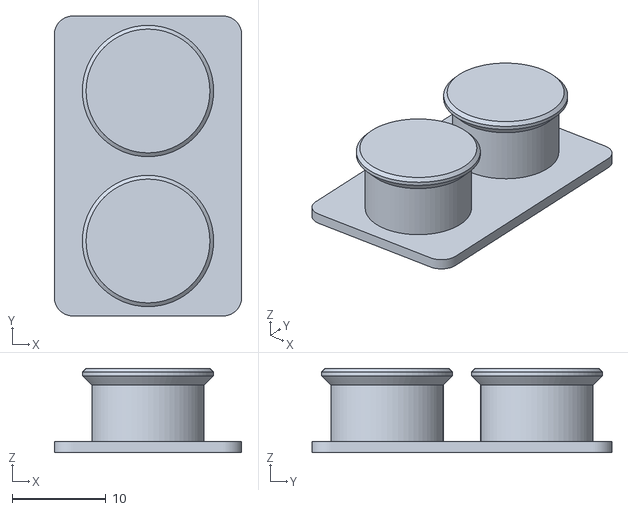
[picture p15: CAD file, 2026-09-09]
hardware/enclosure/delta_collar_v0_3_cable_guide.stl
20.0 x 32.0 x 9.00

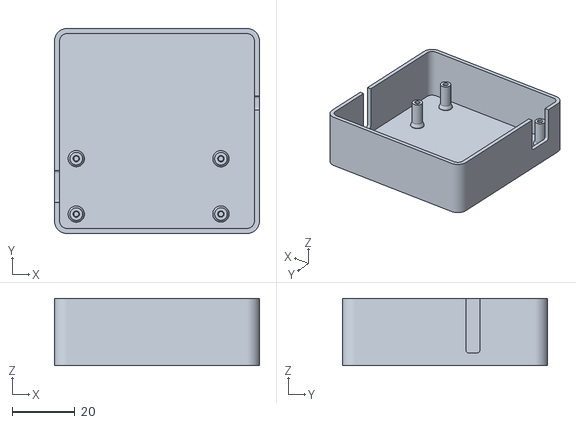
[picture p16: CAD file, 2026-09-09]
hardware/enclosure/v0_4/delta_collar_v0_4_base.stl
65.2 x 65.2 x 21.4

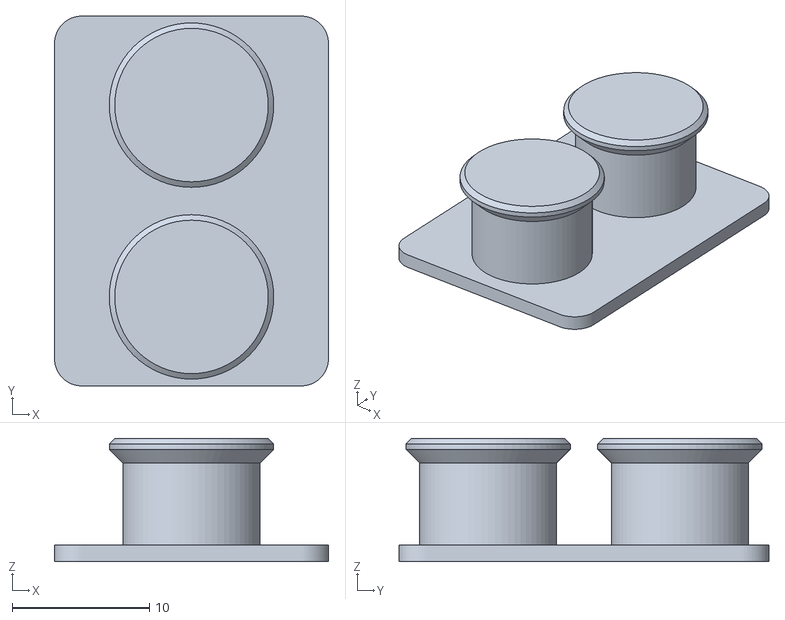
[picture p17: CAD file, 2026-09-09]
hardware/enclosure/delta_collar_v0_3_cable_guide_27mm.stl
20.0 x 27.0 x 9.00

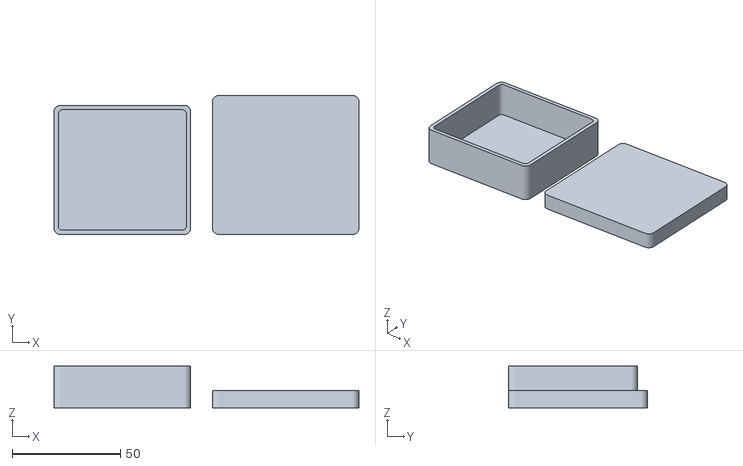
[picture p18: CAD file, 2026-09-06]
hardware/enclosure/delta_collar_enclosure_v1_1.stl
141.2 x 64.4 x 19.3

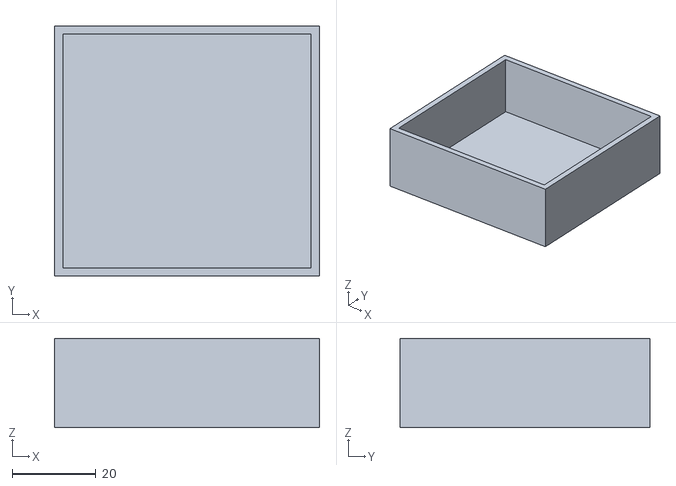
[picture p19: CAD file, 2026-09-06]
hardware/enclosure/delta_collar_enclosure_v0_1_test_tray.stl
63.3 x 59.8 x 21.3

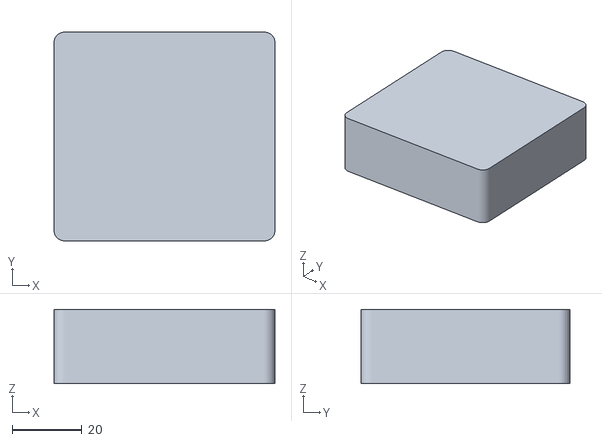
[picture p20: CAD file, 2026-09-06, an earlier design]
hardware/enclosure/delta_collar_enclosure_v1.stl
63.3 x 59.8 x 21.3

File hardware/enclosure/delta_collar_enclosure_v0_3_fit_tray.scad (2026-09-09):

// v0.3 measured low-wall tray, 2026-09-08. Units: mm.
// POWERLESS FIT ONLY. Open top, no lid, fasteners, or powered-use retention.
// Dimensions: external 65.25 x 65.25 x 11.60; cavity 62.05 x 62.05 x 10.00.
// Rebuild with generate_v0_3_fit_tray.py after changing measured/design inputs.
// IMU is nested: assembly height 16.36, not Feather height + IMU height.
// Cable-end allowance 8.0 is provisional, not a measured bend radius.
show_guides = true; // Preview-only component envelopes; excluded from STL exports.
outer_profile = [[61.250000000,0.000000000],[61.642068561,0.019261093],[62.030361288,0.076858878],[62.411138709,0.172238657],[62.780733729,0.304481870],[63.135586947,0.472314943],[63.472280932,0.674121551],[63.787573137,0.907958187],[64.078427125,1.171572875],[64.342041813,1.462426863],[64.575878449,1.777719068],[64.777685057,2.114413053],[64.945518130,2.469266271],[65.077761343,2.838861291],[65.173141122,3.219638712],[65.230738907,3.607931439],[65.250000000,4.000000000],[65.250000000,61.250000000],[65.230738907,61.642068561],[65.173141122,62.030361288],[65.077761343,62.411138709],[64.945518130,62.780733729],[64.777685057,63.135586947],[64.575878449,63.472280932],[64.342041813,63.787573137],[64.078427125,64.078427125],[63.787573137,64.342041813],[63.472280932,64.575878449],[63.135586947,64.777685057],[62.780733729,64.945518130],[62.411138709,65.077761343],[62.030361288,65.173141122],[61.642068561,65.230738907],[61.250000000,65.250000000],[4.000000000,65.250000000],[3.607931439,65.230738907],[3.219638712,65.173141122],[2.838861291,65.077761343],[2.469266271,64.945518130],[2.114413053,64.777685057],[1.777719068,64.575878449],[1.462426863,64.342041813],[1.171572875,64.078427125],[0.907958187,63.787573137],[0.674121551,63.472280932],[0.472314943,63.135586947],[0.304481870,62.780733729],[0.172238657,62.411138709],[0.076858878,62.030361288],[0.019261093,61.642068561],[0.000000000,61.250000000],[0.000000000,4.000000000],[0.019261093,3.607931439],[0.076858878,3.219638712],[0.172238657,2.838861291],[0.304481870,2.469266271],[0.472314943,2.114413053],[0.674121551,1.777719068],[0.907958187,1.462426863],[1.171572875,1.171572875],[1.462426863,0.907958187],[1.777719068,0.674121551],[2.114413053,0.472314943],[2.469266271,0.304481870],[2.838861291,0.172238657],[3.219638712,0.076858878],[3.607931439,0.019261093],[4.000000000,0.000000000]];
inner_profile = [[61.250000000,1.600000000],[61.485241137,1.611556656],[61.718216773,1.646115327],[61.946683225,1.703343194],[62.168440238,1.782689122],[62.381352168,1.883388966],[62.583368559,2.004472930],[62.772543882,2.144774912],[62.947056275,2.302943725],[63.105225088,2.477456118],[63.245527070,2.666631441],[63.366611034,2.868647832],[63.467310878,3.081559762],[63.546656806,3.303316775],[63.603884673,3.531783227],[63.638443344,3.764758863],[63.650000000,4.000000000],[63.650000000,61.250000000],[63.638443344,61.485241137],[63.603884673,61.718216773],[63.546656806,61.946683225],[63.467310878,62.168440238],[63.366611034,62.381352168],[63.245527070,62.583368559],[63.105225088,62.772543882],[62.947056275,62.947056275],[62.772543882,63.105225088],[62.583368559,63.245527070],[62.381352168,63.366611034],[62.168440238,63.467310878],[61.946683225,63.546656806],[61.718216773,63.603884673],[61.485241137,63.638443344],[61.250000000,63.650000000],[4.000000000,63.650000000],[3.764758863,63.638443344],[3.531783227,63.603884673],[3.303316775,63.546656806],[3.081559762,63.467310878],[2.868647832,63.366611034],[2.666631441,63.245527070],[2.477456118,63.105225088],[2.302943725,62.947056275],[2.144774912,62.772543882],[2.004472930,62.583368559],[1.883388966,62.381352168],[1.782689122,62.168440238],[1.703343194,61.946683225],[1.646115327,61.718216773],[1.611556656,61.485241137],[1.600000000,61.250000000],[1.600000000,4.000000000],[1.611556656,3.764758863],[1.646115327,3.531783227],[1.703343194,3.303316775],[1.782689122,3.081559762],[1.883388966,2.868647832],[2.004472930,2.666631441],[2.144774912,2.477456118],[2.302943725,2.302943725],[2.477456118,2.144774912],[2.666631441,2.004472930],[2.868647832,1.883388966],[3.081559762,1.782689122],[3.303316775,1.703343194],[3.531783227,1.646115327],[3.764758863,1.611556656],[4.000000000,1.600000000]];
difference() {
    linear_extrude(height=11.60000) polygon(outer_profile);
    translate([0,0,1.60000])
        linear_extrude(height=11.00000) polygon(inner_profile);
}
if (show_guides) {
    %color([0.2,0.5,0.9,0.4]) translate([3.6,3.6,1.6])
        cube([52.05,22.8,16.36]);
    %color([0.9,0.6,0.2,0.4]) translate([3.6,29.400000000000002,1.6])
        cube([35.9,32.25,4.8]);
}

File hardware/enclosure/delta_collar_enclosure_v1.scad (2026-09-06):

// delta_collar_enclosure_v1.scad
// Parametric starting point for the Stage 1B smaller 3D-printed enclosure.
// Delta collar project.
// See docs/2026-09-06_stage1b_printer_arrival_and_enclosure_kickoff.md
//
// v0.2 - 2026-09-06: split into a two-part BASE + LID (slip-over skirt lid,
// like a shoebox lid), confirmed after v0.1 rendered correctly in OpenSCAD
// but turned out to be a fully sealed shell with no way to insert parts.
// No fasteners or glue -- matches the "close the lid gently, don't force it"
// approach already used for the larger off-the-shelf enclosure.
//
// Layout (unchanged from v0.1):
//   - LSM6DSOX is mounted to the UNDERSIDE of the Feather (taped back-to-back,
//     matching docs/2026-08-14_stage1_enclosure_bench_and_calibration.md),
//     so it adds to the STACK HEIGHT under the Feather, not to the footprint.
//   - Feather sits at the "top" of the base footprint, LiPo sits beside/below
//     it in the same length-wise lane, both flat on the base floor.
//
// IMPORTANT: all dimensions below are still NOMINAL values pulled from
// public Adafruit product pages, NOT measurements of the actual parts.
// High-precision calipers are arriving 2026-09-07 -- update every variable
// below marked "verify" with the real measurement before finalizing v0.3.
// This v0.2 is still for a physical dry-fit / lid-fit test print, not a
// final assembly: no switch cutout or cable strain relief yet.

// ---------- Component nominal dimensions (mm) ----------
feather_l = 52.3; feather_w = 22.8; feather_h = 7.2; // bare PCB only -- verify
feather_header_clearance = 3.0; // extra height for soldered headers -- verify
feather_usb_overhang = 3.0;     // USB-C connector overhang beyond board edge -- verify

lsm6dsox_l = 25.6; lsm6dsox_w = 17.8; lsm6dsox_h = 4.6; // verify
imu_mount_gap = 1.0; // double-sided tape / standoff gap between Feather underside and IMU -- verify

lipo_l = 36; lipo_w = 29; lipo_h = 4.75; // add roughly 10-15 percent thickness margin -- verify

// JST switch and STEMMA QT cable clearances are not published by Adafruit.
// These are placeholders -- measure the real parts before relying on them.
jst_switch_l = 25; jst_switch_w = 10; jst_switch_h = 6; // verify
cable_bend_clearance = 8; // minimum radius to keep STEMMA QT cable from a sharp bend -- verify

// ---------- Base layout ----------
wall_t = 2.0;              // wall thickness -- tune for your printer/material
board_gap = 4.0;           // gap between the Feather lane and the LiPo lane
headroom = 1.5;            // clear space above the tallest internal stack, below the open top
foam_pad_thickness = 3;    // neoprene foam pad thickness on the dog-facing side (added after printing, not printed)

feather_stack_h = feather_h + feather_header_clearance + imu_mount_gap + lsm6dsox_h;

internal_l = max(feather_l + feather_usb_overhang, lipo_l) + 4; // + margin for cable routing
internal_w = feather_w + board_gap + lipo_w;
internal_h = max(feather_stack_h, lipo_h) + headroom;

base_external_l = internal_l + 2 * wall_t;
base_external_w = internal_w + 2 * wall_t;
base_external_h = internal_h + wall_t; // floor only -- top stays open, lid covers it

echo(str("Base external (approx, mm): ", base_external_l, " x ", base_external_w, " x ", base_external_h));

// ---------- Lid: slips down over the OUTSIDE of the base, like a shoebox lid ----------
lid_fit_clearance = 0.3; // per-side gap so the lid slides over the base -- tune after test fit
lid_skirt_h = 6;         // how far the lid overlaps down over the base wall for grip -- verify feels secure
lid_top_t = wall_t;      // lid top thickness

lid_cavity_l = base_external_l + 2 * lid_fit_clearance;
lid_cavity_w = base_external_w + 2 * lid_fit_clearance;
lid_outer_l = lid_cavity_l + 2 * wall_t;
lid_outer_w = lid_cavity_w + 2 * wall_t;
lid_outer_h = lid_skirt_h + lid_top_t;

echo(str("Lid external (approx, mm): ", lid_outer_l, " x ", lid_outer_w, " x ", lid_outer_h));

// ---------- Shared shape helper ----------
module rounded_box(l, w, h, r) {
    hull() {
        for (x = [r, l - r])
            for (y = [r, w - r])
                translate([x, y, 0])
                    cylinder(r = r, h = h, $fn = 32);
    }
}

// ---------- Base: open-top tray ----------
module base_shell() {
    difference() {
        rounded_box(base_external_l, base_external_w, base_external_h, 3);
        // cavity extends above the top face so the top is fully open
        translate([wall_t, wall_t, wall_t])
            rounded_box(internal_l, internal_w, internal_h + 1, 2);
    }
}

// ---------- Lid: cap with a skirt that slips over the base ----------
module lid_shell() {
    difference() {
        rounded_box(lid_outer_l, lid_outer_w, lid_outer_h, 3);
        // cavity from the bottom up through the skirt height, leaving a solid top cap
        translate([wall_t, wall_t, 0])
            rounded_box(lid_cavity_l, lid_cavity_w, lid_skirt_h + 1, 2);
    }
}

// ---------- Render: base on the left, lid on the right, both flat on the bed ----------
base_shell();

translate([base_external_l + 10, 0, 0])
    lid_shell();

// ---------- Component placement guides on the base (visual dry-fit reference only) ----------
// Feather lane (top of footprint)
%translate([wall_t + 2, wall_t + 2, wall_t + imu_mount_gap + lsm6dsox_h])
    cube([feather_l, feather_w, feather_h]);

// LSM6DSOX taped to the Feather underside -- shown touching the base floor,
// with the Feather sitting on top of it (component-side up). Flip this if
// the real assembly is mounted the other way up.
%translate([wall_t + 2 + (feather_l - lsm6dsox_l) / 2, wall_t + 2 + (feather_w - lsm6dsox_w) / 2, wall_t])
    cube([lsm6dsox_l, lsm6dsox_w, lsm6dsox_h]);

// LiPo lane (below the Feather lane in Y), resting flat on the base floor
%translate([wall_t + 2, wall_t + feather_w + board_gap, wall_t])
    cube([lipo_l, lipo_w, lipo_h]);

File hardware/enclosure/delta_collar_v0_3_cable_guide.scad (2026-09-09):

// v0.3 add-on, 2026-09-09: removable two-post cable guide. Units mm.
// Attach underneath to the tray with existing foam tape after powerless fit.
// Post radius is a design trial, not a verified wire bend-radius specification.
$fn=64;
plate_l=20.0; plate_w=32.0; plate_h=1.2; plate_r=2.0;
core_r=6.0; core_h=6.0; lip_r=7.0;
flare_h=1.0; rim_h=0.4; bevel_h=0.4;
module base() {
    hull() for(x=[plate_r,plate_l-plate_r]) for(y=[plate_r,plate_w-plate_r])
        translate([x,y,0]) cylinder(r=plate_r,h=plate_h);
}
module post() {
    rotate_extrude() polygon([[0,plate_h-0.01],[core_r,plate_h-0.01],
        [core_r,plate_h+core_h],[lip_r,plate_h+core_h+flare_h],
        [lip_r,plate_h+core_h+flare_h+rim_h],
        [lip_r-bevel_h,plate_h+core_h+flare_h+rim_h+bevel_h],
        [0,plate_h+core_h+flare_h+rim_h+bevel_h]]);
}
union() { base(); for(y=[8,24]) translate([10,y,0]) post(); }

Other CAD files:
hardware/enclosure/delta_collar_v0_3_cable_guide_27mm.scad
hardware/enclosure/v0_4/assembly.scad

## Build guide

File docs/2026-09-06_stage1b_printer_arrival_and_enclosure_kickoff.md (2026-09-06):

# Stage 1B Progress Update - 3D Printer Arrival And Enclosure Kickoff - 2026-09-06

This note picks up from `docs/2026-08-14_stage1_enclosure_bench_and_calibration.md`. Read this file at the start of the next working session.

## Status Since Last Update (2026-08-14)

- No firmware or bench-test changes were found since the last enclosure bench report. The larger Zulkit enclosure (90 x 70 x 28 mm) remains the only enclosure that has passed the full bench sequence (powerless dry fit, enclosed USB, enclosed battery, four-minute motion calibration).
- The local working copy currently shows line-ending-only differences (CRLF vs the LF stored in Git) across most tracked text files. No content actually changed; safe to leave alone or normalize later with a `.gitattributes` entry. Not addressed in this update.
- `git pull` could not be verified from the automated assistant session used to write this note (network access to github.com is blocked from that environment). The local `HEAD` (`457c923`, "Update Stage 1B progress in README") matches the last known `origin/main` from the previous session. Run `git pull` from a normal terminal to confirm nothing has changed upstream since 2026-08-14.

## New Milestone

The 3D printer has arrived. This unblocks the "smaller 3D-printed enclosure" step that the 2026-08-14 report identified as the gating item before any dog-worn test.

## Reference Component Dimensions (For Enclosure CAD)

Pulled from public Adafruit product pages. Treat these as a starting point only; verify every value with calipers on the actual parts before finalizing the design. Extra clearance is still needed for soldered headers, the USB-C connector overhang, and cable strain relief.

| Component | Nominal size (L x W x H) | Source |
|---|---|---|
| ESP32 Feather V2 (PID 5400) | 52.3 x 22.8 x 7.2 mm | Adafruit product page |
| LSM6DSOX STEMMA QT breakout (PID 4438) | 25.6 x 17.8 x 4.6 mm | Adafruit product page |
| 3.7 V 500 mAh LiPo (PID 1578) | 36 x 29 x 4.75 mm nominal | Adafruit product page |
| JST-PH 2-pin switch cable, STEMMA QT cables | Not published | Measure directly |

Board height figures above are bare-PCB thickness; add clearance for soldered headers, the USB-C receptacle, and the STEMMA QT connector shrouds on both boards.

## Recommended Next Steps

1. Printer bring-up: run the printer's own first-print / bed-leveling routine and one calibration cube before printing anything functional, since this is a brand-new machine.
2. Measure the real parts with calipers: the Feather (with headers and USB-C seated), the LSM6DSOX breakout, the LiPo, the JST switch body, and the minimum STEMMA QT cable bend radius. Record the actual numbers next to the nominal table above.
3. Decide the internal layout (Feather and LiPo side by side vs. stacked) and update `hardware/enclosure/delta_collar_enclosure_v1.scad` (added in this update) with the measured dimensions.
4. Print a shell-only test (no lid fasteners yet) to check dry fit against the real components before committing to a final version.
5. Re-run the same validation sequence used for the larger enclosure, in order, before any dog-worn test:
   - Powerless dry fit.
   - Enclosed USB bench test, 15 minutes.
   - Enclosed battery-only bench test, 15 minutes.
   - Four-minute motion calibration.
6. Only after all four checks pass, proceed to a short supervised collar-fit test per the existing Safety Limits in the README.

## Files Added In This Update

- `hardware/enclosure/delta_collar_enclosure_v1.scad`: a parametric OpenSCAD starting point for the smaller enclosure, using the nominal dimensions above. Open it in OpenSCAD, adjust the dimension variables at the top after measuring the real parts, and export an STL from there. The current geometry is a placeholder shell with component-outline guides only; it has no lid split line, switch cutout, cable strain relief, or strap slots yet.

## Safety Status

Unchanged from the 2026-08-14 report: this remains an engineering prototype, not a veterinary diagnostic device. No dog-worn testing until the smaller enclosure passes the same bench sequence as the current larger enclosure.

## Same-Day Update: OpenSCAD Verified, Base/Lid Split, Mounting Plan (later on 2026-09-06)

The v0.1 parametric model was rendered and exported in OpenSCAD on the real
machine (2021.01) and loaded correctly in Bambu Studio, confirming the
nominal math above: external shell 63.3 x 59.8 x 21.3 mm, matching the
computed values exactly.

That v0.1 shape turned out to be a fully sealed box (no way to insert
parts). It was replaced with a v0.2 two-part design:

- Base: an open-top tray, 63.3 x 59.8 x 19.3 mm nominal, holding the
  Feather (+ LSM6DSOX taped underneath) and the LiPo.
- Lid: a slip-over skirt cap (like a shoebox lid), 67.9 x 64.4 x 8.0 mm
  nominal, no fasteners or glue, matching the "close it gently, do not force
  it" approach already used for the larger off-the-shelf enclosure. Fit
  clearance between base and lid is a placeholder (0.3 mm per side) to be
  tuned after a real print.

Both parts render and export together from
hardware/enclosure/delta_collar_enclosure_v1.scad and loaded correctly in
Bambu Studio (combined bounding box 141.2 x 64.4 x 19.3 mm, matching base
width + 10 mm gap + lid width).

Mounting plan: the real ESP32 HUZZAH32 Feather V2 has four corner mounting
holes (photographed 2026-09-06), not the header pins. Plan is to add four
printed standoff pegs in the base at the real hole positions, each with an
optional pilot hole down the middle so an M2.5 screw can be added later
without reprinting if a plain press-fit peg does not hold securely enough
under motion. This avoids relying on the 2.54 mm header pins, which are a
poor fit for FDM-printed sockets: tight tolerance, no spring contact, wear
out with repeated insertion.

Open question carried to tomorrow: the header pins are soldered through the
board and may protrude significantly on one side (up to roughly 8-9 mm for
stacking-style long headers) or only a few mm (short solder tails).
feather_header_clearance = 3.0 in the model is an unverified placeholder
and may be too small. Needs a real measurement before the internal height
is trusted.

## Updated Caliper Measurement List For 2026-09-07

In addition to the list earlier in this document, measure and report:

- Header pin protrusion on both sides of the Feather board (solder-tail
  side and mating-pin side).
- The four corner mounting hole diameters and the two center-to-center
  spacings (along the long edge and along the short edge).

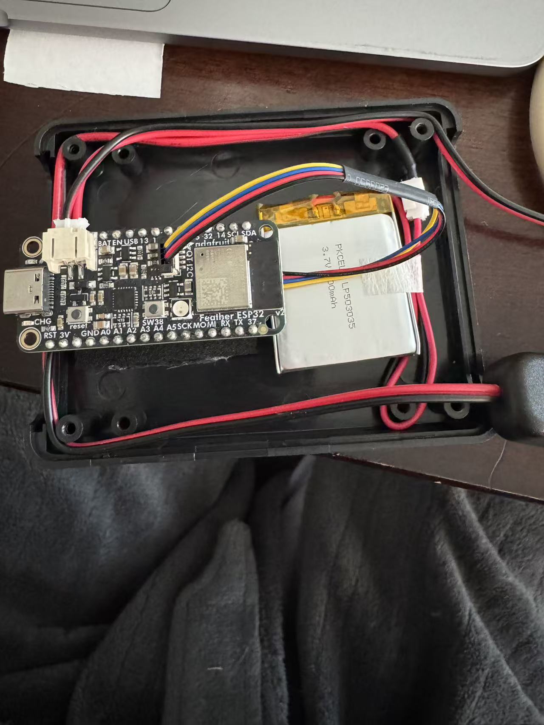
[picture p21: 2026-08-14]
hardware/reference_images/stage1_enclosure_internal_wiring_2026-08-14.jpg

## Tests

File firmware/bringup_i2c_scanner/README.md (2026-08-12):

# ESP32 I2C bring-up

This is the first hardware check for the Stage 1 collar. It scans the ESP32 Feather V2 STEMMA QT I2C bus every three seconds and reports detected addresses through USB serial at 115200 baud.

With the LSM6DSOX connected by a STEMMA QT/Qwiic cable, expect the sensor at `0x6A` or `0x6B`.

## Run

1. Keep the LSM6DSOX connected to the Feather STEMMA QT port.
2. From this directory, run `pio run --target upload`.
3. Run `pio device monitor` to see the scan output.

The firmware only reads the I2C bus. It does not change the IMU configuration.

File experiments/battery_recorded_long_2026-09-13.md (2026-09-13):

# Battery-powered long recording — 2026-09-12/13

## Purpose

Verify that the assembled Delta prototype can continuously sample and save IMU
data on its LiPo for at least one hour, then return the session to the private
website without a cable-side export.

## Procedure

- The board was charged over USB, then USB was removed with the external
  battery switch left on.
- After the board rebooted on battery and rejoined home Wi-Fi, a manual
  recording (`bfe0a2f2`) was started through the local recorder endpoint at
  2026-09-12 21:57:09.
- The device was left stationary. The intended duration was one hour, but the
  operator returned later than planned and reconnected USB at about 02:59.
- The private website was inspected after reconnecting; it had already received
  and integrity-checked the immutable binary file at 00:19:44.

## Results

| Measure | Result |
|---|---:|
| Website record span | 130 min 38 s (7,838 s) |
| Valid samples | 150,289 |
| Whole-span effective rate | 19.174 Hz |
| Reported sampling gaps | 6 min 19 s (4.84% of span) |
| Activity classification | 130 min 38 s rest; walk/run 0 s |
| Activity index | 1.5 mg |
| Battery during saved record | 3.83 V to 3.59 V |
| Website file size | 3,522.4 KiB |
| Cloud file integrity | Passed by the website |

The website labels the record as not normally ended. Its duration ended around
00:07:47, well before the later USB reconnect, and the recorder had begun with
about 3.76 MiB free. The observed 3.52 MiB file size and the firmware's
reserve-based recorder behavior make **storage-full automatic stop** the most
likely explanation. This is an inference from the timing, website status, and
firmware behavior; the device-side file had already been cloud-confirmed and
pruned before inspection, so its final local status marker was no longer
available.

After USB was reconnected, the board rebooted and initially reported 3.322 V.
It rose to 3.464 V over the following roughly two minutes, confirming that the
charger was active on this connection.

## Conclusion

**PASS for the one-hour recorded battery requirement.** The session exceeded
the target by 70 min 38 s, persisted 150k samples, survived low-voltage runtime,
and reached the private website with an integrity-checked binary. It does not
demonstrate a controlled one-hour manual stop, and the current recorder's
practical capacity is about 130 minutes at the observed sampling rate.

The next product validation is a short supervised real walk: begin on battery,
leave the home network, return home, and confirm automatic close/upload and the
website summary. Keep the recording below roughly one hour so the session ends
under normal control rather than at its storage limit.

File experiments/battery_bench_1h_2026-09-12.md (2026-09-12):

# Battery-only bench run — 2026-09-12

## Result

**PASS for one-hour unattended battery runtime.** After the user removed USB
power and later reconnected it, the board's persisted battery log contained one
continuous battery-powered segment lasting **3,781.961 s** (63 min 02 s). It
had 127 voltage samples with no backwards uptime jump, so no reset occurred
during the run.

| Measurement | Result |
|---|---:|
| Duration | 63 min 02 s |
| Battery-log rows | 127 |
| Logged interval, median | 30.020 s |
| Logged interval, range | 29.254–30.050 s |
| Start voltage | 3.914 V |
| End voltage | 3.756 V |
| Lowest observed voltage | 3.732 V |
| Voltage change | -0.158 V |

The board then rejoined the home Wi-Fi. A local status query reported the IMU
ready, 3.7 MiB free recording space, no current recording, and no pending cloud
upload. The private website continued to show the device at home.

## Method

The existing firmware appends its battery-voltage reading to LittleFS every 30
seconds. After USB was reconnected, its read-only `/api/battery-log` endpoint
was retrieved and the segment beginning at 3.914 V was identified by the
monotonic `millis()` timestamps. The next segment begins after USB power was
restored, so it is excluded.

`battery_v` is the Feather's onboard voltage-divider reading. It is useful for
the trend here, but it is not a calibrated state-of-charge estimate.

## Scope and remaining work

This run proves unattended battery supply, voltage logging, and the absence of
a reset for more than one hour. It did **not** trigger a motion recording:
there is no new session in the cloud history. It therefore does not test
full-rate sampling gaps, flash writing during a continuous one-hour record, or
automatic upload of such a record.

The next technical validation is a one-hour **manual recording** on battery
power, followed by reconnecting at home and checking its session, sampling-gap
distribution, voltage trend, and automatic upload. Dog-worn testing remains
deferred until the user resumes it.

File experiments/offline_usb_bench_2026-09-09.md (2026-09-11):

# 离线记录首次实机验证 — 2026-09-09

结论：新固件已刷入 Feather，USB 桌面短测通过**实际关闭 Wi-Fi 后继续保存、完整下载、重启后记录保留**的检查。
实测采样平均约 18.97 Hz，闪存同步会造成间隔抖动；不是严格恒定的 20 Hz。
这是 USB 供电和 EN 复位测试，尚未完成一小时电池续航或实际断电测试。

今日装配、软件和图片总览见 [日报](../docs/2026-09-09_daily_report.md)。

实测累计样本和采样间隔

按已保存的样本时间戳重建累计计数；绿色范围包含关闭无线到确认重连的过程。
图源和聚合数据可复现：[绘图脚本](plot_offline_bench.py)、[汇总 JSON](results/offline_usb_bench_2026-09-09_summary.json)。

## 升级与数据保留

- 板子：ESP32-PICO-V3-02 / Feather ESP32 V2，8 MB Flash。
- USB：`/dev/cu.usbserial-59680111041`，监视波特率 115200。
- 刷机前导出旧电池日志并读取整个 8,388,608 字节闪存。460800 波特读取遇到一次串口包错误；改为 230400 后完整读取成功，后续上传也使用 230400。
- 实际旧分区地址、大小与保留方案一致；上半区 4 MiB 经备份逐字节检查均为 `0xff`。
- 新固件、分区表正常上传，上传工具对各写入段报告 hash 验证通过；没有执行全片擦除。
- 升级前 560 条电池日志与升级后文件的前 560 条逐行一致；测试后共 570 条。
- 整片备份 SHA-256：`b6d8b37bc1ddef412fe1e41f260cf1d69aff3cfb54bf761cf49a91bb8ebbdfc4`。
- 已上传固件：919,232 字节，SHA-256 `9cef35dd935d95efd7d6da102eceec00045d1287d8d9c1a207d3ceaca121ac7d`。

整片备份包含设备设置，保存在 Git 忽略的本地目录中；未上传 GitHub。

## 两分钟记录

使用 [验证脚本](validate_offline_recorder.py)。主记录编号 **`f35506a5`**，本地时间约 20:20:35 开始。

| 检查项 | 实测结果 |
|---|---|
| 记录跨度 | 120,093 ms |
| 保存样本 | 2,279 条 |
| 有效平均采样率 | 18.973 Hz，以首尾时间戳和样本数计算 |
| 相邻间隔 | 中位数 50 ms，最小 3 ms，最大 387 ms |
| 大于 100 ms 的间隔 | 54 段，合计 7,202 ms |
| 原始文件 | 54,728 字节，正好为 32 + 2,279 × 24 |
| CSV / 二进制 | 记录数相同；独立解码后时间戳、状态和各数值一致（数值比较容差 0.0002） |
| CRC、时间戳 | 所有完整记录通过校验；时间戳单调递增 |
| 固件读写错误 | 测试串口未发现 `ERROR`，读取错误计数为 0 |
| IMU 芯片温度 | 30.3789～32.3086 °C，不作为动物体温或长期温升结论 |

主原始文件 SHA-256：`771dd5b28367d880400bf51242a9ee462d47fb3851de489ba45dbedb6e2dcac5`。

## 无线关闭与恢复

- 约第 30 秒通过串口 `O` 关闭 ESP32 的 Wi-Fi，已写入计数为 560。
- 约第 60 秒，串口状态显示同一个记录仍在进行，已写入计数为 1,140；此时 HTTP 请求不可达。
- 约第 90 秒通过 `W` 恢复无线，同一记录继续进行，重新连接后计数为 1,757。
- 约第 120 秒正常停止，再下载 CSV 和二进制；记录期间尝试下载时返回 409，避免传输阻塞正在采集的记录。
- 原有家庭 Wi-Fi 设置保留，恢复连接成功。`O`/`W` 只影响临时无线状态，不修改凭据。

## 重启与真实网页

正常停止的 `f35506a5` 在一次 EN 硬件复位后重新下载，二进制文件逐字节相同。
另新建 `67c84763`，约 4.35 秒后在未停止记录的情况下触发 EN 复位：复位后显示 `interrupted`，80 条已同步记录全部可独立解码。
这验证了重启恢复，**不是直接切断供电的验证**。

真实设备 `/records` 页面在手机尺寸 390 px 和桌面浏览器下检查通过，无页面脚本错误或手机横向溢出。
主记录的整段曲线显示 2,279 条样本，约 1.9 分钟低活动，未覆盖约 7.2 秒。
这里的未覆盖时间来自初始间隔和大于 100 ms 的间隔；不能算作静止或活动时间。
此桌面记录不用于验证犬类行为识别。

真实设备两分钟记录的手机尺寸报告

测试结束时 Wi-Fi 已恢复，记录已停止，未删除测试或旧记录。重启会自动开始新的记录。

## 已知限制与下一步

1. 当前同步写入会阻塞主循环，造成高于 100 ms 的采样间隔及随后较短的间隔。已有时间戳如实保留这些间隔；需要固定频率行为分析时，应先将采样与闪存写入解耦并复测。
2. 仍需一小时桌面电池记录，核对实际续航、完整文件、采样间隙和存储占用。页面剩余容量估计不是电池续航。
3. 直接断电尾部恢复和实际存储写满停止尚未在设备上验证；不能用主机模拟或 EN 复位替代这些结论。
4. 用户目前明确暂缓佩戴和上狗测试。

原始证据位于本地 `data/raw/offline_upgrade_20260909_201050/`：备份及上传日志、固件快照、`bench/result.json`、串口日志、CSV/BIN、重启中断记录和真实网页截图。
该目录被 Git 忽略，新克隆不会包含这些设备数据。

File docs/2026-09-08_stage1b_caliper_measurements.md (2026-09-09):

# Stage 1B：卡尺到货与实物测量 — 2026-09-08

## 本次进度

- 已从 GitHub fast-forward 同步 `main`：`457c923` → `7b54d0d`。
- 同步了 9 月 6 日进度记录、OpenSCAD 参数模型和三个 STL 文件。
- 用户确认游标卡尺已到货，并提供第一轮实测尺寸，记录如下。
- IMU 曾取下单独测量，现已由用户从侧面滑入 Feather 背面排针座之间。用户确认当前为无胶、无绝缘垫层的机械卡持，手感非常牢固；组合总高仍为原先的 16.36 mm。此状态的电气隔离及运动下的固定可靠性尚未验证。
- 已收到开关尺寸。用户倾向将开关外置，当前外壳规划不为开关本体预留内部空间；外置固定方式尚待确定。
- 当前为 Stage 1B 外壳小型化。现有大外壳已通过断电试装、15 分钟 USB、15 分钟电池及 4 分钟手持动作测试。
- 已完成当前无胶机械卡持装配的两分钟 USB 串口观测，保存 2,370 条样本，未发现固件错误或启动后的再次复位；见下方测试结果链接。小外壳配合、1 小时电池测试和该长测的完整数据采集仍待完成。

最新状态汇总见 [9 月 9 日工作交接](2026-09-09_stage1b_handoff.md)。本文同时保留测量与装配判断的修正过程。

## 测量方法（后续补测时使用）

拔掉 USB，关闭开关并断开电池。卡尺擦净、闭合归零，统一使用 mm。
不要为测量强拆当前卡持的 IMU；优先测整个组件的外包络。
金属量爪不要碰电池插头的两个触点，不要夹压电池软包；电池厚度仅轻触估读。
每项重复测量两次；记录读数，不要先把设计余量加到实测值里。

| 项目 | 实测值（mm，空白为待测） | 测量说明 |
|---|---|---|
| Feather PCB 长 × 宽；整板总高（含焊接公插，不含 IMU） | 51.57 × 22.80；16.36 | 总高不是 PCB 板厚；51.57 不含 USB 突出部分 |
| Feather 含 USB 金属接口总长 | 52.05 | 比 PCB 长 0.48 mm；不含外接 USB 线插头及插拔空间 |
| Feather PCB 板厚 | | 板厚只量板材，避开器件和焊点 |
| Feather 上侧排针突出高度 | 1.18 | 用户报告的上侧，保留原始方向定义 |
| Feather 下侧排针／焊脚突出高度 | 9.10 | 用户报告的下侧，保留原始方向定义 |
| IMU 长 × 宽 × 高（单独测量） | 25.51 × 17.82 × 4.71 | 已侧向滑入排针塑料座之间；用户明确无胶、无绝缘垫层 |
| Feather + IMU 当前组合总高 | 16.36 | 用户确认与原 Feather 含排针高度一致，IMU 未超过原高度包络；不再额外加 4.71 mm |
| 当前组合含连接器、走线的总长 × 总宽 | | 线材出口包络尚未给出；不能把 PCB 尺寸等同于插线后的总包络 |
| 四个安装孔直径 | 左侧有金属圈两孔：2.45；右侧无金属圈两孔：2.52 | 以用户照片为准：USB 在左，元件面朝向镜头 |
| 四孔中心位置 | 见下方推算坐标 | 根据已确认的孔内缘到板边距离推算，尚未经打印试装验证 |
| 安装孔下方可用空间 | 9 月 9 日用户确认右侧两孔下方能放支撑柱，IMU 无遮挡 | 更新先前仅凭照片的可能遮挡判断；柱径和四孔对位仍需 v0.4 实物试装 |
| 背面两排金属针内侧距离 | 19.59 | 用户更正：只量了金属针之间，未包含向内占用空间的黑色塑料座；不是有效安装净宽 |
| 背面两排黑色塑料座间净宽 | | 尚无实测数值；不能用 19.59 mm 代替 |
| LiPo 长 × 宽 × 厚 | 35.90 × 32.25 × 4.80 | 宽度包含贴在长边的一段电线，作为当前布局外包络保留 |
| JST 开关长 × 宽 × 高 | 45.05 × 15.89 × 15.19 | 高度包含 OFF 状态按钮；当前按外置规划，不计入盒内组件包络；ON 状态及完整操作空间未测 |
| USB 线插头外壳宽 × 高 | 8.95 × 3.30 | 9 月 9 日补测；实际外壳为金属 |
| Feather 白色电池插头超出 PCB 长边 | 1.06 | 硬塑料部分，不含软线；软线回弯高度待试放 |
| 开关线束合计自然宽 × 厚 | 3.32 × 1.59 | 全部出盒线材仍需一起试放槽口 |
| STEMMA 接头／软线弯曲包络 | | 精确形状与绕线高度未量，按现有插接状态试放 |
| 项圈宽 × 厚、固定带宽 × 厚 | | 用于后续绑带槽设计 |

孔中心不方便直接量时，可量 PCB 边缘到孔近边的距离，再加半个孔径。
同径两孔的中心距也可用外侧总距减一个孔径；不要把孔边距当成中心距。
线材保持自然弯曲，只记录布局所需空间，不要折线寻找极限弯曲半径。

第一轮组件、排针、孔位与电池测量已完成。后续若补测孔位，可附标明 USB 方向和孔编号的俯视照片，减少坐标歧义。

## 安装孔原始读数与推算位置

用户照片中 USB 位于左侧，左边两孔有金属圈，右边两孔无金属圈。
用户已确认以下距离从孔内缘量到板边，不从金属圈外缘或孔中心起量：

| 孔组 | 到宽边（短边）的距离 | 到长边的距离 |
|---|---:|---:|
| 左侧有金属圈两孔 | 1.63 mm | 1.34 mm |
| 右侧无金属圈两孔 | 1.42 mm | 1.34 mm |

孔中心间距是两个圆孔圆心之间的距离，用于定位外壳固定柱。
根据已确认的孔内缘到板边距离和 PCB 长度 51.57 mm，推算如下：

- 左孔中心距左短边：1.63 + 2.45 / 2 = 2.855 mm。
- 右孔中心距右短边：1.42 + 2.52 / 2 = 2.680 mm。
- 左右孔沿板长方向中心距：51.57 - 2.855 - 2.680 = 46.035 mm。
- 左侧上下孔中心距：22.80 - 2 × (1.34 + 2.45 / 2) = 17.67 mm。
- 右侧上下孔中心距：22.80 - 2 × (1.34 + 2.52 / 2) = 17.60 mm。

以照片中 PCB 左短边为 x=0、上长边为 y=0，x 向右、y 向下（不以 USB 接口外缘为原点）：

| 孔 | 推算中心 (x, y)，mm |
|---|---|
| 左上，有金属圈 | (2.855, 2.565) |
| 左下，有金属圈 | (2.855, 20.235) |
| 右上，无金属圈 | (48.890, 2.600) |
| 右下，无金属圈 | (48.890, 20.200) |

这些是按用户每组两孔共用读数推算的坐标，额外小数位来自运算，不代表测量精度。
小差异可能来自测量误差，不据此认定孔位不对称；后续需试装验证。
按实测占地设计的 v0.3 低侧壁托盘已通过用户实物并排试放；上述孔坐标已用于 v0.4 四柱模型，实物对孔待验证。
已收到侧向滑入照片和 19.59 mm 测量起点更正。用户确认无绝缘层、组合总高仍为 16.36 mm；安装孔支撑通道后来已确认，板间电气接触与运动保持仍待实际核对。

## 背面照片检查

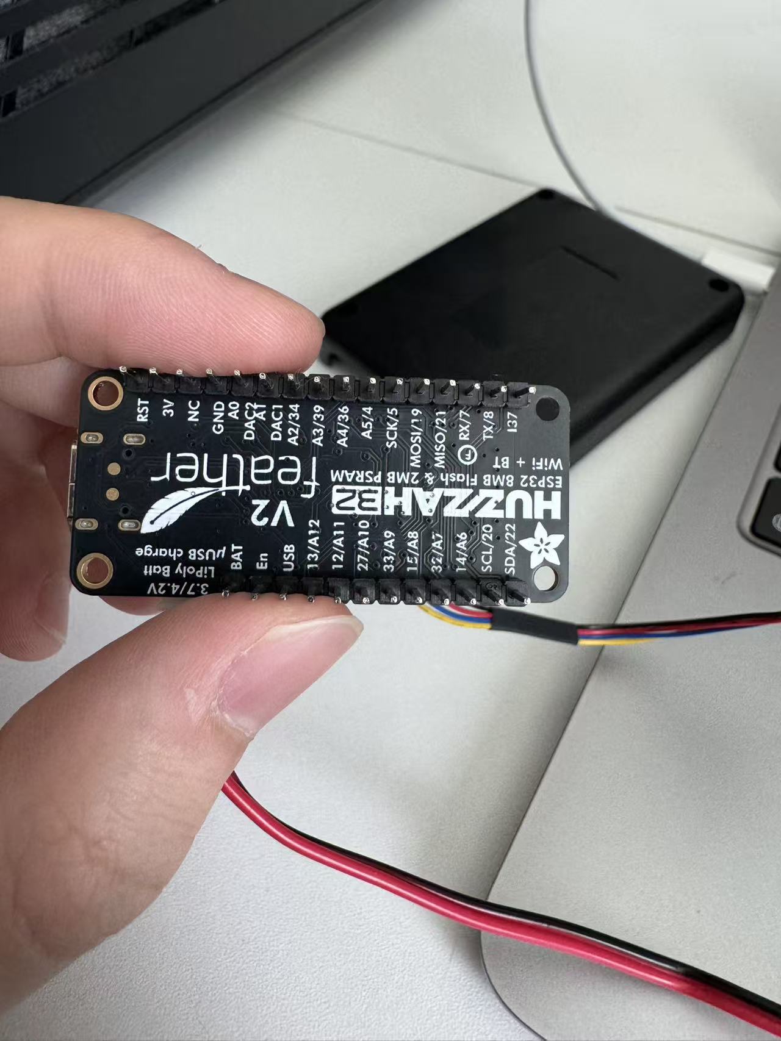
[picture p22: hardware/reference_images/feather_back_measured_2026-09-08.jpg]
Feather 背面实物


来源：用户于本次测量对话提供的背面照片，已保存在仓库内。
上面的孔位坐标仍采用此前正面照片的方向，不能直接用背面照片的上下方向替换。

- 四个角孔均可见；可继续以四孔支撑为设计候选，但照片不能验证柱体与相邻排针的间隙。
- 两条长边各有一排排针／塑料座，中部没有明显的大器件，仍可见焊盘等导电部位。
- 照片不提供可靠的净宽或垂直间隙数值，不据此认定 IMU 能嵌入排针之间。
- 用户最初报告 19.59 mm，随后澄清这只是金属针之间的距离，忽略了黑色塑料座。此前据此推算的总余量 1.77 mm／每侧约 0.89 mm 不适用于实际安装净宽，已撤回。
- 后续用户已确认 IMU 嵌入后仍在原排针高度包络内，组合总高沿用 16.36 mm；当前无需重复索取同一高度。只有改变隔离层或安装结构后，才需要复核是否超出这一包络。

### 后续实际试放与修正

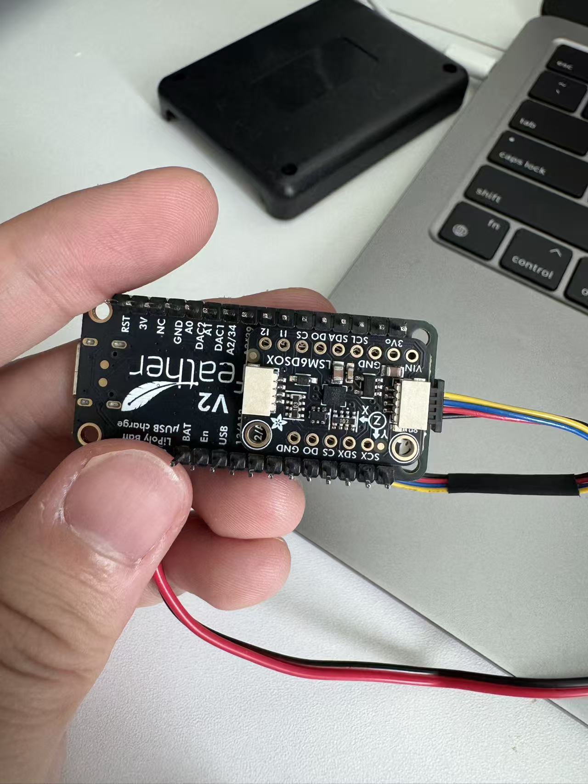
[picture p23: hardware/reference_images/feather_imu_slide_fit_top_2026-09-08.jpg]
IMU 侧向滑入后的背面布局


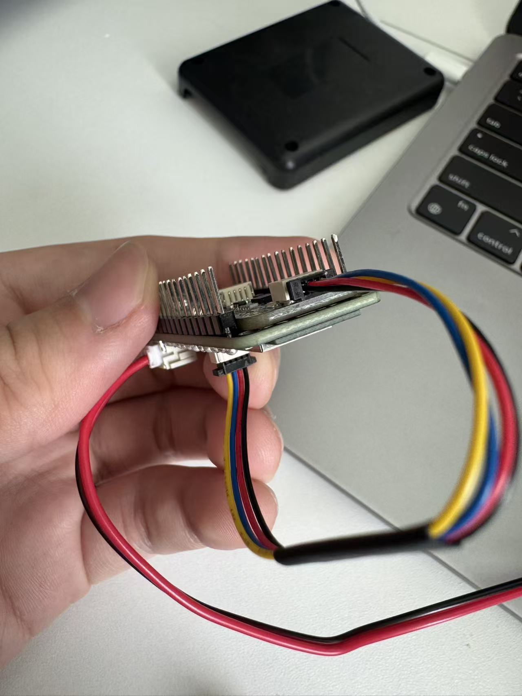
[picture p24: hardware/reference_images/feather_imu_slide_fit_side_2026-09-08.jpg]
IMU 侧向滑入后的侧视图


用户报告：从上方直接贴合时放不下，从侧面推入后能刚好卡在黑色塑料座之间，侧面与背部贴合紧密。进一步确认未使用任何胶、胶带、双面胶或绝缘垫层，完全依靠机械卡持，手感非常牢固；IMU 嵌入针脚之间未增加高度，总高仍为 16.36 mm。此处记录用户装配观察，不是运动可靠性或通电检查通过。

- 照片显示 IMU 位于 Feather 背面靠右的位置，连接线向右伸出；高度按用户确认值记录，线材弯曲包络尚未提供，不按照片比例推算。
- 更正此前照片解读：侧视图的层状外观不能认定为额外垫层；用户已明确没有添加材料。Feather 背面照片可见裸露焊盘，紧密贴合本身不能证明两板导电部位已隔离；确认隔离前保持 USB 和电池断开。
- 不要求必须用胶固定；机械固定方案仍可继续评估。但“卡得很牢”只说明当前手感，尚未证明运动时的保持力或板上受力合适。如果装入需要撑开排针座、压弯板子或刮擦焊点，则调整布局，不继续强推。
- 背面俯视图中 IMU 靠近并可能遮挡 Feather 右下安装孔区域；IMU 自己的孔不视为与 Feather 孔同轴。四孔支撑仍需逐孔确认通道。

板间电气隔离可以通过可靠固定的间隔材料，或使裸露导电部位保持间隙的独立支撑实现，不强制增加专用绝缘膜或新采购。不要把额外材料强塞进现有紧配合。当前 16.36 mm 是组件高度基准，不是盒内净高，完整外壳仍需底部与顶部装配间隙。当前 v0.3 仅用于断电占地试装，支撑设计仍需避开右侧孔区的潜在干涉。

### 现有双面胶与下一步选择

用户说明手头只有采购清单中的双面胶，没有另购绝缘材料。采购记录为“3M 1/2 inch foam double-sided mounting tape”，未记具体产品型号和厚度。8 月 14 日旧组装记录也曾使用双面胶作为板间机械隔垫，但这不是当前胶带型号电气性能的认证。

- 不要求一定有单独的绝缘层；需要保证两板可能相碰的裸露导电部位不会接触，可靠的支撑间隙也是一种办法。
- 现有泡棉双面胶可作为间隔与固定候选，但不要求为加胶强行拆开当前卡持结构；不要仅凭品牌认定胶带的绝缘等级。
- 若采用胶层，应避开尖锐焊脚，确保胶层不会被刺穿或挤到两板金属相碰，留出安装孔和插头位置。不要求涂满两块板，但需要实际检查全部可能接触的导电部位。
- 当前侧向卡位较紧，若加入泡棉胶后无法自然放入，就改支撑布局；不要为了保持 16.36 mm 而强行挤压。重新布置后只有超出原包络时才修订高度。

参考：[Adafruit LCD Backpack 组装说明](https://learn.adafruit.com/i2c-spi-lcd-backpack/assembly)在其板间接触场景中建议用电工胶带或泡棉胶带避免元件短接。这支持泡棉隔垫的原型装配思路，不证明本项目这卷未识别型号的胶带具有特定绝缘额定值。

### 最新决定：保留当前卡持，先验证再定布局

用户说明当前卡得很紧，取出困难，希望先测试再决定布局。保留该偏好：不要求为加入双面胶强拔 IMU，也不强行塞入胶层。

- 当前可继续断电机械试装：确认整体是否平直、四孔支撑位置、底部和盖子间隙、接头及外置开关走线；16.36 mm 继续作为当前组件高度。
- 通电与否取决于是否排除了板间意外导电接触，不取决于是否用了胶。侧面照明检查时需看清相对的焊盘、焊脚、金属孔圈与针脚；照片尚不足以确认隐藏接触面的情况。
- 若接触区可检查且确认不存在金属误接触、针脚受挤弯等问题，可以开始短时、有人看护的开放式 USB 台架测试，电池保持物理断开；先静置观察数据、异常复位及发热，再决定后续动作测试。USB 供电也不是短路保护的保证。
- 若关键接触区无法看清，则暂不直接以插电池或 USB 的方式试错；继续断电布局验证，另行安排断电电气检查或可控的拆装。普通“能启动／有数据”不能证明无意外接触或长期机械可靠性。
- 上述路径制定时尚未执行测试；随后用户发起 USB 测试，结果记录如下。

### 已完成：两分钟 USB 串口观测

详见 [测试报告](../experiments/usb_slide_fit_2min_2026-09-08.md)。用户在测试中确认电池已断开，未发现异常发热、异味或板子明显弯曲。采集得到 2,370 条有效样本，约 19.98 Hz；启动后无时间戳回退，无固件错误。IMU 内部温度范围 29.08–31.45°C，末段静止加速度模长 0.9918–0.9969 g。

本次仅证明该窗口内基本功能正常；板间绝缘、机械固定耐久性及完整外壳验证仍未完成。当前无需为补胶强拆，但不能把此次功能结果当作这些项目已通过。

## 开关外置设计方向

按用户当前偏好，盒内不容纳开关本体，不为按钮设计盒壁操作开口。
仍需为开关连接线进出盒体预留通道，并设计出口护边及线材应力释放。
外置开关需要独立固定，避免悬挂拉扯连接器；固定位置和方式待布局时确定。
记录的 15.19 mm 仅为 OFF 状态外包络，不代表完整按钮操作包络。

## 收到尺寸后的工作

1. 将真实外包络与当前 CAD 参数对应，避免板高、排针和 IMU 高度重复相加。
2. 根据孔位和下方空间设计支撑，检查电池平放、走线及外置开关线材出口。
3. 更新模型后导出新的底盒／盖子，先做断电试装与盖子配合检查。
4. 配合确认后完成固定、外置开关固定、线材出口与应力释放和项圈固定结构，再重复原有台架验证顺序；通过前不进行 Delta 佩戴测试。

注意：旧记录把 7.2 mm 和 4.6 mm 写成“bare-PCB thickness”，不可直接当作板材厚度使用。旧 v0.1／v1／v1_1 STL 未按本次实测修订；新生成的 v0.3 试装托盘采用了本次实测占地。

## 已准备：v0.3 低侧壁试装托盘

文件与操作见 [外壳目录说明](../hardware/enclosure/README.md)。托盘外尺寸 65.25 × 65.25 × 11.60 mm，内部平面 62.05 × 62.05 mm、侧壁内高 10 mm；板组与电池旁置，开关外置。此版用于检查占地、线材和柱位通道，不是完整高度的最终外壳。

STL 网格与尺寸核对通过，尚未做 Bambu 切片或实物打印。下一步导入 STL、切片打印并断电试装，反馈俯视／侧面照片及干涉位置。

后续更新（2026-09-09）：用户已完成打印并确认可以并排放下，仍有空余空间，提出增加绕线柱。新的试装照片、双柱理线座及下一步操作见 [9 月 9 日记录](2026-09-09_stage1b_tray_fit_and_cable_routing.md)。

再次补测（2026-09-09）：用户确认当前 IMU 不遮挡 Feather 右侧两个安装孔，下方可放柱子；这更新了前文仅凭照片所作的潜在遮挡判断。实际 USB 线插头金属外壳为 8.95 × 3.30 mm，通往外置开关的线束合计自然宽 × 厚为 3.32 × 1.59 mm。已将这些值用于 [v0.4 带盖试装版](../hardware/enclosure/v0_4/README.md)，实物柱位和合盖尚待检查。

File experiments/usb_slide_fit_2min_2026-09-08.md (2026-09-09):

# IMU 背面机械卡持：两分钟 USB 串口观测 — 2026-09-08

## 结论

本次短时 USB 串口功能检查未发现固件报错、启动后的再次复位或持续数据中断。静置阶段 IMU 数据稳定。
这支持继续做外壳机械试装，不代表板间绝缘、卡持耐久性、长时间温升或佩戴安全已经验证。

## 装配与方法

- IMU 从侧面滑入 Feather 背面排针塑料座之间，无胶、无额外绝缘层；用户确认组合总高仍为 16.36 mm。
- 用户发起 USB 测试，并在采集中确认电池已断开，未发现异常发热、异味或板子明显弯曲。表面温度未独立测量。
- 串口：`/dev/cu.usbserial-59680111041`，115200 baud。
- 本地采集开始时间：2026-09-08 15:54:05（America/New_York），记录窗口约 120.5 秒。
- 只读取串口，没有发送固件命令、清空板内日志或刷写固件。打开串口前设置 DTR/RTS 为非激活状态。
- 开始时捕获一次 `POWERON_RESET` 启动序列；串口打开与启动同时发生，不能确定启动原因。首条样本设备时间为 1,129 ms，此后没有时间戳回退。
- 采集中约前半段出现未经脚本标记的动作信号，可能与拿取检查有关；本次不作为完整的静态标定或正式动作标定。
- 最初一次读取因主机权限失败，未收到样本；获得串口访问权限后才开始本次有效采集，该主机权限事件不计作设备故障。

## 数据结果

| 指标 | 结果 |
|---|---:|
| 有效 CSV 样本 | 2,370 |
| 样本覆盖设备时间 | 118.560 s |
| 平均输出频率 | 19.981 Hz |
| 观测到的固件 ERROR／panic／brownout／watchdog 文本 | 0 |
| 首次启动后设备时间戳回退 | 0 |
| 畸形数值行 | 0 |
| 最大相邻设备样本间隔 | 0.122 s |
| IMU 内部温度范围 | 29.08–31.45°C |
| 首／末 10 秒平均 IMU 温度 | 29.280／31.352°C |
| 末条 IMU 温度 | 31.42°C |
| 全程加速度模长范围 | 0.5260–1.4680 g |
| 全程陀螺仪模长峰值 | 380.79°/s |
| 后 60 秒样本数 | 1,200 |
| 后 60 秒加速度模长范围 | 0.9918–0.9969 g |
| 后 60 秒陀螺仪模长峰值 | 0.746°/s |

IMU 温度缓慢上升，结束时仍有上升趋势，两分钟不足以确定热平衡。
其读数不是 Feather 所有器件或外壳表面温度。电池已断开，因此 CSV 中约 4.176–4.198 V 的 `battery_v` ADC 读数不作实际电池电压解释。

## 数据文件

- 逐样本 CSV：`data/raw/usb_slide_fit_20260908_155405.csv`
- 完整串口文本：`data/raw/usb_slide_fit_20260908_155405.log`
- 统计与装配元数据：`data/raw/usb_slide_fit_20260908_155405.json`

以上路径相对仓库根目录，原始数据按仓库现有规则保存在本地、被 Git 忽略；GitHub 仅包含本报告，重新克隆仓库不会获得这些原始文件。
观测完成后已关闭串口读取，并提示用户拔掉 USB；未远程确认 USB 已拔掉。

## 下一步

保留当前装配作为机械试装参考，按已记录尺寸继续底盒、固定位置及走线设计。
板间导电接触检查仍待完成；不因短时功能正常而标记该项通过。后续 9 月 9 日用户已确认 IMU 不遮挡右侧孔、下方能放支撑柱；四柱实物对位仍待打印试装。
布局确认后，再按项目既定顺序完成外壳内的 USB、电池及动作验证。

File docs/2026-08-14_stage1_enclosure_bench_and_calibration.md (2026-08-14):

# Stage 1 Enclosure Bench And Calibration - 2026-08-14

This report records the first successful enclosed bench tests for the Delta
collar prototype. The larger ABS enclosure was dry-fitted, tested on USB,
tested on battery power, and then used for a short hand-motion calibration.

## Summary

| Check | Result |
|---|---|
| Powerless enclosure dry fit | PASS |
| Enclosed USB bench, 15 min | PASS |
| Enclosed battery-only bench, 15 min | PASS |
| Four-minute motion calibration | PASS |
| First dog-worn test | Deferred |

The electronics operated normally in the enclosure. No reset, data alert,
wireless dropout, odor, hot spot, LiPo swelling, LiPo dent, or wire pinch was
observed during the completed tests.

The first dog-worn test is intentionally deferred. The current enclosure is
functional for bench work but still feels too large for Delta. The next
mechanical step is a smaller 3D-printed enclosure before any on-dog test.

## Hardware Layout

Reference photo:

- `hardware/reference_images/stage1_enclosure_internal_wiring_2026-08-14.jpg`

Summary figure:

- `docs/figures/stage1_enclosure_bench_summary_2026-08-14.svg`

The summary figure was generated from 30-second monitor summaries and phase
summaries captured during testing. Raw per-sample CSV was not saved for this
session, so the figure should be treated as a trend summary rather than a
full-resolution data trace.

Stage 1 enclosure bench summary

Observed layout:

- ESP32 Feather/HUZZAH32 V2 mounted in the larger enclosure with USB-C near the
  enclosure edge for bench access.
- Adafruit LSM6DSOX IMU fixed to the back side of the ESP32 board using
  double-sided tape.
- 3.7 V 500 mAh LiPo placed flat inside the enclosure.
- JST inline switch and battery leads routed around the enclosure edge.
- STEMMA QT cable routed with a gentle bend between ESP32 and IMU.

Safety checks before power:

- LiPo remained flat and removable.
- No forced lid closure was required.
- No visible battery compression, board-edge pressure, or wire pinch was
  observed after the powerless dry fit.
- The IMU-to-ESP32 tape layer was checked as an insulating/mechanical spacer.

## Enclosed USB Bench Test

Purpose: verify that the assembled enclosure can run from USB power without
rapid heat rise, resets, stream failures, or mechanical pressure symptoms.

Setup:

- USB-C connected.
- Battery switch kept OFF.
- Enclosure lightly closed, not used on Delta.
- ESP32 monitored through USB serial.

Result: PASS.

| Measurement | Result |
|---|---:|
| Duration | 901 s |
| Valid samples | 17,948 |
| Resets | 0 |
| Alerts | 0 |
| IMU temperature range | 34.11 to 40.64 C |
| End IMU temperature | about 34.18 C |
| Battery voltage trend while on USB | about 4.200 to 4.198 V |
| Motion magnitude range | 0.7666 to 1.3162 g |

Notes:

- After restart, the internal IMU temperature peaked near 40.64 C and then
  settled down to about 34.2 C by the end of the test.
- Static `motion_g` remained around 0.987 to 0.988 g. A few motion spikes were
  consistent with touching or moving the enclosure, not with a device fault.
- Physical post-check found no LiPo dent, swelling, odor, hot spot, or wire
  pinch.

## Enclosed Battery-Only Bench Test

Purpose: verify that the assembled enclosure can run from the LiPo without USB
power while streaming over Wi-Fi.

Setup:

- USB disconnected.
- Battery switch ON.
- Enclosure lightly closed, not used on Delta.
- ESP32 monitored through the dashboard API at `http://172.24.23.82/api/latest`.

Result: PASS.

| Measurement | Result |
|---|---:|
| Duration | 900 s |
| API samples | 1,791 |
| Network misses | 0 |
| Resets | 0 |
| Alerts | 0 |
| IMU temperature range | 30.33 to 31.04 C |
| Battery voltage trend | 3.994 to 3.916 V |
| Battery voltage range | 3.914 to 4.000 V |
| Motion magnitude range | 0.8653 to 1.0675 g |

Notes:

- Battery-only operation ran cooler than USB operation.
- Wi-Fi stayed connected for the full test window.
- Physical post-check again found no LiPo swelling, no dents, no odor, no hot
  spots, and no visible wire or connector issue.

## Four-Minute Motion Calibration

Purpose: confirm that the IMU remains mechanically coupled inside the enclosure
and that the current activity score separates stillness from hand motion.

Setup:

- USB disconnected.
- Battery switch ON.
- Dashboard API polled at roughly 4 Hz.
- Three phases:
  - 0:00-2:00 still on desk.
  - 2:00-3:00 gentle hand-held movement.
  - 3:00-4:00 gentle turns, starts, and stops.

Result: PASS.

| Phase | Samples | Motion magnitude | Activity score | Gyro magnitude | State counts |
|---|---:|---:|---:|---:|---|
| Still | 350 | 0.9879 to 0.9919 g | avg 0.0223, max 0.0240 | avg 0.44 dps, max 0.52 dps | Resting 350 |
| Hand movement | 188 | 0.6592 to 1.3201 g | avg 0.1829, max 0.6149 | avg 28.46 dps, max 146.01 dps | Active 93, Resting 95 |
| Turn/stop | 193 | 0.7263 to 1.3444 g | avg 0.3304, max 0.7988 | avg 75.02 dps, max 324.97 dps | Active 186, Resting 7 |

Overall connection result:

| Measurement | Result |
|---|---:|
| Duration | 240 s |
| Samples | 731 |
| Network misses | 1 |
| Resets | 0 |
| Alerts | 0 |
| End battery voltage | 3.904 V |

Conclusion:

- The still baseline was clean and consistently classified as Resting.
- Gentle motion and turning produced clearly higher activity scores.
- The IMU mount was stable enough for continued bench calibration.

## Current Decision

The current enclosure is acceptable for bench tests but is larger than desired
for a first dog-worn trial. The dog-worn collar test is deferred until a smaller
3D-printed enclosure is designed and built.

This decision does not block continued Stage 1 engineering work. It only delays
comfort validation and real dog-worn motion data collection.

## Recommended Stage 1B Work

Proceed with bench and design work before any on-dog test:

1. Run a longer battery-only runtime test, starting with 1 hour.
2. Add test labels or session metadata to dashboard CSV exports.
3. Build a small analysis script for battery trend, motion score, and state
   summary.
4. Measure the exact dimensions of the Feather, LiPo, IMU, JST switch, cable
   bends, and required lid clearance.
5. Draft a smaller 3D-printable enclosure concept with:
   - Flat, non-compressed LiPo placement.
   - Removable battery access.
   - Strain relief for JST and STEMMA QT cables.
   - External access to the power switch.
   - Dog-facing foam contact surface.
   - No hard strap head or screw feature on the dog-facing side.
6. Keep dog-worn testing blocked until the smaller enclosure passes the same
   dry fit, USB enclosed, battery enclosed, and motion calibration sequence.

## Safety Status

This remains an engineering prototype, not a veterinary diagnostic device.
Charging should only be done attended, through the Feather's onboard charger,
with the enclosure open and the battery not compressed. Do not charge while
worn or while the enclosure is closed.

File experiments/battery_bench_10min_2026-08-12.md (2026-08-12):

# Battery Bench Test - 2026-08-12

## Purpose

Verify that the ESP32 Feather V2 and LSM6DSOX can run from the 3.7 V 500 mAh LiPo battery for ten minutes after USB power is removed.

## Setup

- LiPo connected to the Feather through the JST-PH inline switch.
- Switch set to ON.
- LSM6DSOX connected through STEMMA QT.
- Board and battery kept on a desk with no enclosure.
- `firmware/imu_raw_stream` recorded battery voltage to internal flash every 30 seconds.

## Result

The test passed.

| Measurement | Result |
|---|---:|
| Battery-only logged duration | 599.31 s |
| Battery-only voltage range | 3.936 to 3.908 V |
| Voltage change during test | -0.028 V |
| Battery-only log records | 21 |

The device started a new uptime sequence at 759 ms when USB was removed. This is a power-source transition boundary, not a reset during the battery-only run. The following records continued without another reset through 600,068 ms.

The `battery_v` value is an approximate voltage from the Feather's onboard divider. It supports trend checking but is not a calibrated state-of-charge measurement. The 4.196 V record before the battery-only sequence was taken while USB was attached and is excluded from the battery-only comparison.

## Conclusion

The LiPo, JST switch, Feather, IMU, and internal voltage logging operated normally over the monitored ten-minute battery run. This is a short bench-supply test, not yet a full runtime or wearable validation.

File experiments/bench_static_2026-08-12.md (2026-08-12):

# Bench Static Test - 2026-08-12

## Purpose

Verify that the ESP32 Feather V2, LSM6DSOX, STEMMA QT connection, and USB serial data path remain stable during a ten-minute desk-rest test.

## Setup

- ESP32 Feather V2 powered by USB-C.
- LSM6DSOX connected through the Feather STEMMA QT port.
- `firmware/imu_raw_stream` configured the IMU for 104 Hz at +/-4 g and +/-500 deg/s.
- Firmware emitted CSV samples at 20 Hz.
- Board and sensor remained on a desk without intentional movement.

## Result

The test passed.

| Measurement | Result |
|---|---:|
| Logged duration | 599.95 s |
| Samples | 12,003 |
| Invalid serial lines | 0 |
| Sample rate | 20 Hz |
| Motion magnitude | 0.9828 to 1.0750 g |
| Peak gyroscope magnitude | 80.82 deg/s |

The host terminal could not keep a single ten-minute serial process alive, so data was captured in four 150-second windows. The ESP32 stayed powered throughout. Its device timestamp increased from 863,992 ms to 1,554,642 ms across all windows, confirming that it did not reset. The 27.0-32.4 second gaps are host-side logging gaps between windows, not gaps in ESP32 uptime.

The brief 80.82 deg/s peak in the first window is consistent with an external disturbance; all windows had continuous valid data and no I2C errors.

## Raw Data

- `data/raw/bench_static_10min_part1_2026-08-12.csv`
- `data/raw/bench_static_10min_part2_2026-08-12.csv`
- `data/raw/bench_static_10min_part3_2026-08-12.csv`
- `data/raw/bench_static_10min_part4_2026-08-12.csv`

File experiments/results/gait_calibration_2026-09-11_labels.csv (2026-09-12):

# start_s | end_s | label — inferred from the recording | pending the user's confirmation
12 | 118 | rest
130 | 215 | walk
222 | 268 | walk
280 | 340 | rest

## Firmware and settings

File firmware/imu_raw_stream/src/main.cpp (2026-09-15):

#include <Arduino.h>
#include <LittleFS.h>
#include <Preferences.h>
#include <WebServer.h>
#include <WiFi.h>
#include <Wire.h>

#include <math.h>
#include "motion_logger.h"
#include "cloud_sync.h"
#include "records_page.h"

namespace {

constexpr uint8_t kImuAddress = 0x6A;
constexpr uint8_t kWhoAmIRegister = 0x0F;
constexpr uint8_t kCtrl1XlRegister = 0x10;
constexpr uint8_t kCtrl2GRegister = 0x11;
constexpr uint8_t kCtrl3CRegister = 0x12;
constexpr uint8_t kOutputStartRegister = 0x20;
constexpr uint8_t kExpectedWhoAmI = 0x6C;
constexpr unsigned long kSampleIntervalMs = 50;
constexpr unsigned long kBatterySampleIntervalMs = 1000;
constexpr unsigned long kBatteryLogIntervalMs = 30000;
constexpr int kBatteryMonitorPin = 35;
constexpr char kBatteryLogPath[] = "/battery_voltage.csv";
constexpr char kAccessPointSsid[] = "Delta-Collar";
constexpr char kAccessPointPassword[] = "deltacollar";

constexpr float kAccelGPerLsb = 0.000122f;  // +/-4 g range
constexpr float kGyroDpsPerLsb = 0.0175f;  // +/-500 deg/s range

bool batteryLogReady = false;
bool imuReady = false;
MotionLogger motionLogger;
CloudSync cloudSync(motionLogger);
float batteryVoltage = 0.0f;
WebServer server(80);
Preferences preferences;
String stationSsid;
String stationPassword;
bool stationCredentialsNeedSaving = false;
bool accessPointRunning = false;
bool radioEnabled = true;

void startAccessPoint();
void connectToStation(const String& ssid, const String& password, bool saveOnSuccess);

struct ImuSample {
  unsigned long timestampMs = 0;
  float accelX = 0.0f;
  float accelY = 0.0f;
  float accelZ = 0.0f;
  float gyroX = 0.0f;
  float gyroY = 0.0f;
  float gyroZ = 0.0f;
  float temperatureC = 0.0f;
  float motionG = 0.0f;
  float activityScore = 0.0f;
  bool active = false;
  bool valid = false;
};

ImuSample latestSample;

const char kDashboardHtml[] PROGMEM = R"HTML(
<!doctype html>
<html lang="en">
<head>
  <meta charset="utf-8">
  <meta name="viewport" content="width=device-width, initial-scale=1">
  <title>Delta Collar</title>
  <style>
    :root { color-scheme: light; font-family: Arial, sans-serif; color: #1d2a2c; background: #edf1ee; }
    * { box-sizing: border-box; }
    body { margin: 0; }
    header { background: #1e3733; color: #ffffff; padding: 16px max(20px, calc((100vw - 900px) / 2)); }
    h1 { margin: 0; font-size: 22px; font-weight: 700; }
    header p { margin: 4px 0 0; color: #d8e4d9; font-size: 14px; }
    main { max-width: 900px; margin: 0 auto; padding: 18px; }
    .summary { display: grid; grid-template-columns: repeat(5, minmax(0, 1fr)); gap: 10px; }
    .metric, .panel { background: #ffffff; border: 1px solid #d4dcda; border-radius: 6px; }
    .metric { min-height: 84px; padding: 12px; }
    .metric dt { color: #5a6a69; font-size: 12px; }
    .metric dd { margin: 6px 0 0; font-size: 22px; font-variant-numeric: tabular-nums; }
    .metric dd.small { font-size: 16px; line-height: 1.3; }
    .panel { margin-top: 14px; padding: 14px; }
    .panel-header { display: flex; align-items: center; justify-content: space-between; gap: 12px; margin-bottom: 10px; }
    h2 { margin: 0; font-size: 16px; }
    canvas { width: 100%; height: 220px; display: block; background: #fbfcfb; border: 1px solid #e1e7e4; }
    .values { display: grid; grid-template-columns: repeat(3, minmax(0, 1fr)); gap: 10px; font-variant-numeric: tabular-nums; }
    .value { padding: 8px 0; border-top: 1px solid #edf1ee; }
    .label { display: block; color: #5a6a69; font-size: 12px; margin-bottom: 3px; }
    .controls { display: flex; gap: 8px; flex-wrap: wrap; }
    button, a.button { appearance: none; border: 1px solid #2d685a; border-radius: 4px; background: #2d685a; color: #ffffff; cursor: pointer; padding: 8px 10px; font: inherit; font-size: 13px; text-decoration: none; }
    button:hover, a.button:hover { background: #245448; }
    #connection { color: #5a6a69; font-size: 13px; }
    @media (max-width: 620px) {
      .summary { grid-template-columns: repeat(2, minmax(0, 1fr)); }
      .values { grid-template-columns: 1fr; }
      header { padding: 14px 18px; }
      main { padding: 12px; }
    }
  </style>
</head>
<body>
  <header>
    <h1>Delta Collar</h1>
    <p>Live IMU and battery monitor · <a href="/records" style="color:white">离线记录 / 完整历史</a></p>
  </header>
  <main>
    <section class="summary" aria-label="Current status">
      <dl class="metric"><dt>State</dt><dd id="state">Starting</dd></dl>
      <dl class="metric"><dt>Activity score</dt><dd id="activity">--</dd></dl>
      <dl class="metric"><dt>Battery</dt><dd id="battery">--</dd></dl>
      <dl class="metric"><dt>Wi-Fi clients</dt><dd id="clients">--</dd></dl>
      <dl class="metric"><dt>Apartment Wi-Fi</dt><dd id="network" class="small">Not configured</dd></dl>
    </section>
    <section class="panel">
      <div class="panel-header"><h2>Motion activity · recent ~45 seconds</h2><span id="connection">Connecting</span></div>
      <canvas id="chart" width="820" height="220" aria-label="Activity history"></canvas>
    </section>
    <section class="panel">
      <div class="panel-header"><h2>Current reading</h2><div class="controls"><a class="button" href="/setup">Wi-Fi setup</a><button id="download">Download browser CSV</button><a class="button" href="/api/battery-log">Download battery log</a></div></div>
      <div class="values">
        <div class="value"><span class="label">Acceleration (g)</span><span id="accel">--</span></div>
        <div class="value"><span class="label">Gyroscope (deg/s)</span><span id="gyro">--</span></div>
        <div class="value"><span class="label">Temperature</span><span id="temp">--</span></div>
      </div>
    </section>
  </main>
  <script>
    const history = [];
    let lastTimestamp = -1;
    const fmt = (value, digits = 2) => Number(value).toFixed(digits);
    const setText = (id, value) => document.getElementById(id).textContent = value;

    function drawChart() {
      const canvas = document.getElementById('chart');
      const context = canvas.getContext('2d');
      const width = canvas.width;
      const height = canvas.height;
      context.clearRect(0, 0, width, height);
      context.strokeStyle = '#dce5e0';
      context.lineWidth = 1;
      [0.25, 0.5, 0.75].forEach(fraction => {
        const y = height * fraction;
        context.beginPath(); context.moveTo(0, y); context.lineTo(width, y); context.stroke();
      });
      if (history.length < 2) return;
      context.strokeStyle = '#c4582b';
      context.lineWidth = 2;
      context.beginPath();
      history.forEach((sample, index) => {
        const x = (index / (history.length - 1)) * width;
        const y = height - Math.min(1, sample.activity) * (height - 6) - 3;
        index ? context.lineTo(x, y) : context.moveTo(x, y);
      });
      context.stroke();
    }

    function update(sample) {
      setText('state', sample.state);
      setText('activity', fmt(sample.activity, 3));
      setText('battery', fmt(sample.battery_v, 3) + ' V');
      setText('clients', sample.clients);
      setText('network', sample.wifi_connected ? sample.wifi_ip : 'Not connected');
      setText('accel', `${fmt(sample.ax_g, 3)}, ${fmt(sample.ay_g, 3)}, ${fmt(sample.az_g, 3)}`);
      setText('gyro', `${fmt(sample.gx_dps, 1)}, ${fmt(sample.gy_dps, 1)}, ${fmt(sample.gz_dps, 1)}`);
      setText('temp', fmt(sample.temp_c, 1) + ' C');
      if (sample.ms !== lastTimestamp) {
        lastTimestamp = sample.ms;
        history.push(sample);
        if (history.length > 180) history.shift();
        drawChart();
      }
    }

    async function poll() {
      try {
        const response = await fetch('/api/latest', { cache: 'no-store' });
        if (!response.ok) throw new Error('request failed');
        update(await response.json());
        setText('connection', 'Live');
      } catch (error) {
        setText('connection', 'Reconnecting');
      }
    }

    document.getElementById('download').addEventListener('click', () => {
      const header = 'ms,ax_g,ay_g,az_g,gx_dps,gy_dps,gz_dps,temp_c,motion_g,activity_score,battery_v,state';
      const rows = history.map(sample => [sample.ms, sample.ax_g, sample.ay_g, sample.az_g, sample.gx_dps, sample.gy_dps, sample.gz_dps, sample.temp_c, sample.motion_g, sample.activity, sample.battery_v, sample.state].join(','));
      const blob = new Blob([[header, ...rows].join('\n') + '\n'], { type: 'text/csv' });
      const link = document.createElement('a');
      link.href = URL.createObjectURL(blob);
      link.download = 'delta-collar-browser-log.csv';
      link.click();
      URL.revokeObjectURL(link.href);
    });

    poll();
    setInterval(poll, 250);
  </script>
</body>
</html>
)HTML";

const char kNetworkSetupHtml[] PROGMEM = R"HTML(
<!doctype html>
<html lang="en">
<head>
  <meta charset="utf-8">
  <meta name="viewport" content="width=device-width, initial-scale=1">
  <title>Delta Collar Network</title>
  <style>
    :root { font-family: Arial, sans-serif; color: #1d2a2c; background: #edf1ee; }
    * { box-sizing: border-box; } body { margin: 0; }
    main { max-width: 560px; margin: 36px auto; padding: 18px; }
    .panel { background: #fff; border: 1px solid #d4dcda; border-radius: 6px; padding: 18px; }
    h1 { font-size: 22px; margin: 0 0 6px; } p { color: #5a6a69; line-height: 1.45; }
    label { display: block; margin-top: 14px; font-size: 14px; font-weight: 700; }
    input { width: 100%; margin-top: 6px; padding: 10px; border: 1px solid #b9c7c2; border-radius: 4px; font: inherit; }
    .actions { display: flex; gap: 8px; flex-wrap: wrap; margin-top: 18px; }
    button, a { border: 1px solid #2d685a; border-radius: 4px; background: #2d685a; color: #fff; cursor: pointer; padding: 9px 11px; font: inherit; text-decoration: none; }
    button.secondary, a.secondary { background: #fff; color: #2d685a; } #status { min-height: 22px; margin-top: 14px; font-size: 14px; }
  </style>
</head>
<body>
  <main><section class="panel">
    <h1>Apartment Wi-Fi</h1>
    <p id="current">Checking connection...</p>
    <form id="network-form">
      <label for="ssid">Network name</label><input id="ssid" name="ssid" maxlength="32" required autocomplete="off">
      <label for="password">Password</label><input id="password" name="password" type="password" maxlength="63" autocomplete="current-password">
      <div class="actions"><button type="submit">Connect</button><button class="secondary" id="forget" type="button">Forget saved network</button><a class="secondary" href="/">Back to dashboard</a></div>
    </form>
    <div id="status"></div>
  </section></main>
  <script>
    const status = document.getElementById('status');
    const current = document.getElementById('current');
    async function refresh() {
      try {
        const response = await fetch('/api/network', { cache: 'no-store' });
        const network = await response.json();
        current.textContent = network.connected ? `Connected. Dashboard address: http://${network.ip}` : 'Not connected to apartment Wi-Fi yet.';
      } catch { current.textContent = 'Connection status unavailable.'; }
    }
    document.getElementById('network-form').addEventListener('submit', async event => {
      event.preventDefault();
      status.textContent = 'Connecting...';
      const response = await fetch('/api/wifi', { method: 'POST', body: new URLSearchParams(new FormData(event.target)) });
      status.textContent = response.ok ? 'Connection request sent. Wait a few seconds for the dashboard address above.' : await response.text();
      setTimeout(refresh, 5000);
    });
    document.getElementById('forget').addEventListener('click', async () => {
      await fetch('/api/wifi', { method: 'DELETE' });
      status.textContent = 'Saved network removed.';
      refresh();
    });
    refresh();
  </script>
</body>
</html>
)HTML";

bool writeRegister(uint8_t reg, uint8_t value) {
  Wire.beginTransmission(kImuAddress);
  Wire.write(reg);
  Wire.write(value);
  return Wire.endTransmission() == 0;
}

bool readRegisters(uint8_t startRegister, uint8_t* values, size_t length) {
  Wire.beginTransmission(kImuAddress);
  Wire.write(startRegister);
  if (Wire.endTransmission(false) != 0) {
    return false;
  }

  if (Wire.requestFrom(static_cast<int>(kImuAddress), static_cast<int>(length)) !=
      length) {
    return false;
  }

  for (size_t index = 0; index < length; ++index) {
    values[index] = Wire.read();
  }
  return true;
}

int16_t toInt16(uint8_t lowByte, uint8_t highByte) {
  return static_cast<int16_t>((static_cast<uint16_t>(highByte) << 8) | lowByte);
}

bool configureImu() {
  uint8_t whoAmI = 0;
  if (!readRegisters(kWhoAmIRegister, &whoAmI, 1) || whoAmI != kExpectedWhoAmI) {
    return false;
  }

  // Enable block-data update and multi-byte address increment.
  if (!writeRegister(kCtrl3CRegister, 0x44)) {
    return false;
  }

  // 104 Hz, +/-4 g accelerometer; 104 Hz, +/-500 deg/s gyroscope.
  return writeRegister(kCtrl1XlRegister, 0x48) &&
         writeRegister(kCtrl2GRegister, 0x44);
}

float readBatteryVoltage() {
  // GPIO35 reads the Feather's onboard 1:2 LiPo voltage divider.
  return analogReadMilliVolts(kBatteryMonitorPin) * 2.0f / 1000.0f;
}

void appendBatteryLog() {
  if (!batteryLogReady) {
    return;
  }

  File log = LittleFS.open(kBatteryLogPath, FILE_APPEND);
  if (!log) {
    Serial.println("ERROR,battery_log_open_failed");
    return;
  }

  log.printf("%lu,%.3f\n", millis(), batteryVoltage);
  log.close();
}

void dumpBatteryLog() {
  if (!batteryLogReady) {
    Serial.println("ERROR,battery_log_unavailable");
    return;
  }

  File log = LittleFS.open(kBatteryLogPath, FILE_READ);
  if (!log) {
    Serial.println("BATTERY_LOG,empty");
    return;
  }

  Serial.println("BATTERY_LOG_BEGIN,ms,battery_v");
  while (log.available()) {
    Serial.write(log.read());
  }
  log.close();
  Serial.println("BATTERY_LOG_END");
}

void clearBatteryLog() {
  if (!batteryLogReady) {
    Serial.println("ERROR,battery_log_unavailable");
    return;
  }

  LittleFS.remove(kBatteryLogPath);
  Serial.println("BATTERY_LOG,cleared");
}

void handleSerialCommands() {
  while (Serial.available()) {
    static String provisioning;
    static bool receiving = false;
    const char ch = Serial.read();
    if(receiving){
      if(ch=='\n'){Serial.println(cloudSync.configure(provisioning)?"STATUS,cloud_configured":"ERROR,cloud_config_invalid");provisioning="";receiving=false;}
      else if(ch!='\r'){if(provisioning.length()<2048)provisioning+=ch;else{provisioning="";receiving=false;}}
      continue;
    }
    if(ch=='U'){receiving=true;provisioning="";continue;}
    if(ch=='Q'){Serial.println(cloudSync.statusJson());continue;}
    // Timing probe of the site (read-only); prints one STATUS,cloud_timing per request.
    if(ch=='T'){cloudSync.selfTest();continue;}
    switch (ch) {
      case 'D':
      case 'd':
        if (motionLogger.recording()) Serial.println("ERROR,stop_motion_recording_with_S_first");
        else dumpBatteryLog();
        break;
      case 'C':
      case 'c':
        clearBatteryLog();
        break;
      case 'R':
      case 'r':
        if (!imuReady || !cloudSync.startManual(0)) Serial.println("ERROR,motion_start_failed");
        break;
      case 'S':
      case 's':
        motionLogger.stop();
        break;
      case 'L':
      case 'l':
        Serial.println(motionLogger.statusJson());
        break;
      case 'O':
      case 'o':
        // Bench/offline control: retain credentials and the current recording.
        radioEnabled = false;
        WiFi.disconnect(false, false);
        WiFi.mode(WIFI_OFF);
        accessPointRunning = false;
        Serial.println("STATUS,WiFi_off,recording_unchanged");
        break;
      case 'W':
      case 'w':
        radioEnabled = true;
        startAccessPoint();
        connectToStation(stationSsid, stationPassword, false);
        Serial.println("STATUS,WiFi_on,recording_unchanged");
        break;
      case 'N':
      case 'n':
        Serial.printf("STATUS,network,enabled=%d,connected=%d,ip=%s\n", radioEnabled,
                      WiFi.status() == WL_CONNECTED, WiFi.localIP().toString().c_str());
        break;
    }
  }
}

void updateActivity(float motionG, float gyroX, float gyroY, float gyroZ) {
  const float dynamicAcceleration = fabsf(motionG - 1.0f);
  const float gyroMagnitude = sqrtf(gyroX * gyroX + gyroY * gyroY + gyroZ * gyroZ);
  const float rawScore = min(1.0f, dynamicAcceleration * 2.0f + gyroMagnitude / 360.0f);
  latestSample.activityScore = latestSample.activityScore * 0.82f + rawScore * 0.18f;

  if (latestSample.active && latestSample.activityScore < 0.04f) {
    latestSample.active = false;
  } else if (!latestSample.active && latestSample.activityScore > 0.08f) {
    latestSample.active = true;
  }
}

void sendLatestSample() {
  char response[512] = {};
  snprintf(response, sizeof(response),
           "{\"ms\":%lu,\"ax_g\":%.4f,\"ay_g\":%.4f,\"az_g\":%.4f,"
           "\"gx_dps\":%.2f,\"gy_dps\":%.2f,\"gz_dps\":%.2f,"
           "\"temp_c\":%.2f,\"motion_g\":%.4f,\"activity\":%.4f,"
           "\"battery_v\":%.3f,\"state\":\"%s\",\"clients\":%d,"
           "\"wifi_connected\":%s,\"wifi_ip\":\"%s\",\"valid\":%s}",
           latestSample.timestampMs, latestSample.accelX, latestSample.accelY,
           latestSample.accelZ, latestSample.gyroX, latestSample.gyroY,
           latestSample.gyroZ, latestSample.temperatureC, latestSample.motionG,
           latestSample.activityScore, batteryVoltage,
           latestSample.active ? "Active" : "Resting", WiFi.softAPgetStationNum(),
           WiFi.status() == WL_CONNECTED ? "true" : "false",
           WiFi.localIP().toString().c_str(), latestSample.valid ? "true" : "false");
  server.sendHeader("Cache-Control", "no-store");
  server.send(200, "application/json", response);
}

void sendBatteryLog() {
  if (motionLogger.recording()) {
    server.send(409, "text/plain", "Stop motion recording before downloading logs.\n");
    return;
  }
  if (!batteryLogReady) {
    server.send(503, "text/plain", "Battery log unavailable\n");
    return;
  }

  File log = LittleFS.open(kBatteryLogPath, FILE_READ);
  if (!log) {
    server.send(200, "text/csv", "ms,battery_v\n");
    return;
  }

  server.sendHeader("Content-Disposition", "attachment; filename=battery_voltage.csv");
  server.streamFile(log, "text/csv");
  log.close();
}

void saveStationCredentials() {
  preferences.begin("delta-collar", false);
  preferences.putString("wifi_ssid", stationSsid);
  preferences.putString("wifi_pass", stationPassword);
  preferences.end();
  stationCredentialsNeedSaving = false;
  Serial.printf("STATUS,STA_connected,STA_ip=%s\n", WiFi.localIP().toString().c_str());
}

void startAccessPoint() {
  if (accessPointRunning) {
    return;
  }

  WiFi.mode(WIFI_AP_STA);
  if (!WiFi.softAP(kAccessPointSsid, kAccessPointPassword)) {
    Serial.println("ERROR,AP_start_failed");
    return;
  }

  accessPointRunning = true;
  Serial.printf("STATUS,AP_started,AP_ssid=%s,AP_ip=%s\n", kAccessPointSsid,
                WiFi.softAPIP().toString().c_str());
}

void stopAccessPoint() {
  if (!accessPointRunning) {
    return;
  }

  WiFi.softAPdisconnect(true);
  accessPointRunning = false;
  Serial.println("STATUS,AP_stopped,station_connected");
}

void connectToStation(const String& ssid, const String& password, bool saveOnSuccess) {
  if (ssid.isEmpty()) {
    return;
  }

  stationSsid = ssid;
  stationPassword = password;
  stationCredentialsNeedSaving = saveOnSuccess;
  WiFi.setAutoReconnect(true);
  WiFi.begin(stationSsid.c_str(), stationPassword.c_str());
  Serial.printf("STATUS,STA_connecting,STA_ssid=%s\n", stationSsid.c_str());
}

void sendNetworkStatus() {
  char response[192] = {};
  snprintf(response, sizeof(response), "{\"connected\":%s,\"ip\":\"%s\"}",
           WiFi.status() == WL_CONNECTED ? "true" : "false",
           WiFi.localIP().toString().c_str());
  server.sendHeader("Cache-Control", "no-store");
  server.send(200, "application/json", response);
}

void receiveNetworkCredentials() {
  const String ssid = server.arg("ssid");
  const String password = server.arg("password");
  if (ssid.isEmpty() || ssid.length() > 32 || password.length() > 63) {
    server.send(400, "text/plain", "Enter a valid network name and password.\n");
    return;
  }

  connectToStation(ssid, password, true);
  server.send(202, "text/plain", "Connection started.\n");
}

void forgetNetwork() {
  WiFi.disconnect(false, true);
  preferences.begin("delta-collar", false);
  preferences.clear();
  preferences.end();
  stationSsid = "";
  stationPassword = "";
  stationCredentialsNeedSaving = false;
  startAccessPoint();
  Serial.println("STATUS,STA_credentials_cleared");
  server.send(200, "text/plain", "Saved network removed.\n");
}
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
void loop() {
  handleSerialCommands();
  server.handleClient();

  if (stationCredentialsNeedSaving && WiFi.status() == WL_CONNECTED) {
    saveStationCredentials();
  }

  if (radioEnabled && !stationSsid.isEmpty()) {
    if (WiFi.status() == WL_CONNECTED) {
      stopAccessPoint();
    } else {
      startAccessPoint();
      static uint32_t lastReconnect = 0;
      if(millis()-lastReconnect>=15000){lastReconnect=millis();WiFi.reconnect();}
    }
  }

  static unsigned long lastSampleMs = 0;
  const unsigned long now = millis();

  if (imuReady && now - lastSampleMs >= kSampleIntervalMs) {
    lastSampleMs = now;
    printSample();
  }
  motionLogger.tick(millis());
  cloudSync.tick(radioEnabled && WiFi.status() == WL_CONNECTED, imuReady, latestSample.active,
                 batteryVoltage);
}

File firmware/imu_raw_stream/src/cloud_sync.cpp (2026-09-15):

#include "cloud_sync.h"

#include <Preferences.h>
#include <WiFiClientSecure.h>
#include <mbedtls/sha256.h>
#include <sys/time.h>
#include <time.h>

#include <algorithm>

#include "cloud_ca.h"

namespace {
constexpr uint32_t kBootGraceMs = 30000;      // let saved home Wi-Fi connect after power-on
constexpr uint32_t kLeaveDebounceMs = 10000;  // brief Wi-Fi drops at home start nothing
constexpr uint32_t kHomeStableMs = 15000;     // stable home link closes the away session
constexpr uint32_t kStartRetryMs = 30000;
constexpr uint32_t kRetryMs = 30000;
constexpr uint32_t kAuthRetryMs = 300000;
constexpr uint32_t kScanMs = 60000;
constexpr uint32_t kHeartbeatMs = 60000;
constexpr uint32_t kPruneCheckMs = 30000;
// Worn only for outings: movement itself starts a session, because a walk can
// stay inside home Wi-Fi. Sustained means active with no pause longer than the
// gap below; the session then ends after this much stillness at home.
constexpr uint32_t kMotionStartMs = 30000;
constexpr uint32_t kMotionGapMs = 3000;
constexpr uint32_t kStillStopMs = 300000;
constexpr uint32_t kMotionHoldMs = 120000;  // after a session ends at home
constexpr size_t kChunkBytes = 16384;
// About one hour at 20 Hz (1.73 MB) after the recorder's 128 KiB reserve and
// its 15% filesystem allowance. Confirmed sessions are removed first; a local
// oldest-first fallback exists only to keep a long away recording going.
constexpr size_t kPruneTargetBytes = 2300000;
// During a long outing, free more space only when nearly full.
constexpr size_t kPruneLowWaterBytes = 512 * 1024;
constexpr size_t kPruneTopUpBytes = 1024 * 1024;
const char* const kDataExtensions[] = {".bin", ".open", ".full", ".sensor", ".error"};

bool due(uint32_t now, uint32_t at) { return !at || int32_t(now - at) >= 0; }
uint32_t after(uint32_t now, uint32_t delay) {
  const uint32_t at = now + delay;
  return at ? at : 1;
}
bool dataExtension(const String& ext) {
  for (const char* known : kDataExtensions)
    if (ext == known) return true;
  return false;
}
uint64_t headerStart(File& f) {
  uint8_t h[motion::kHeaderBytes];
  if (!f.seek(0) || f.read(h, sizeof(h)) != sizeof(h) || !motion::validHeader(h)) return 0;
  return uint64_t(motion::get32(h + 16)) | (uint64_t(motion::get32(h + 20)) << 32);
}
void removeIfPresent(fs::FS& fs, const String& path) {
  if (fs.exists(path)) fs.remove(path);
}
}  // namespace

void CloudSync::begin() {
  client_.setCACert(kCloudRootCA);
  client_.setHandshakeTimeout(12);
  // Configured once: the TLS handshake costs about 3 s on this board, so the
  // socket is kept for the whole sync burst.
  http_.setReuse(true);
  http_.setConnectTimeout(8000);
  http_.setTimeout(15000);
  http_.setFollowRedirects(HTTPC_DISABLE_FOLLOW_REDIRECTS);
  // Redirects are never followed with credentials; log where the host wanted to
  // send us, and what it says about keeping the connection.
  static const char* kCollect[] = {"Location", "Connection"};
  http_.collectHeaders(kCollect, 2);
  Preferences p;
  if (p.begin("delta-cloud", true)) {
    url_ = p.getString("url", "");
    bypass_ = p.getString("bypass", "");
    token_ = p.getString("token", "");
    p.end();
  }
  enabled_ = url_.startsWith("https://") && bypass_.length() && token_.length() == 64;
  mode_ = enabled_ ? "starting" : "unconfigured";
  // SNTP runs once the station has an IP; uploads wait for a real clock.
  configTime(0, 0, "time.cloudflare.com", "pool.ntp.org", "time.google.com");
}

uint64_t CloudSync::unixMs() const {
  struct timeval t;
  gettimeofday(&t, nullptr);
  return t.tv_sec > 1700000000 ? uint64_t(t.tv_sec) * 1000 + t.tv_usec / 1000 : 0;
}

bool CloudSync::configure(const String& line) {
  const int a = line.indexOf('|');
  const int b = a < 0 ? -1 : line.indexOf('|', a + 1);
  if (b < 0 || line.length() > 2048) return false;
  const String url = line.substring(0, a), bypass = line.substring(a + 1, b),
               token = line.substring(b + 1);
  // One HTTPS origin only; credentials arrive over local USB and are never echoed.
  if (!url.startsWith("https://") || url.length() < 12 || bypass.length() < 16 ||
      bypass.length() > 512 || token.length() != 64)
    return false;
  for (unsigned i = 8; i < url.length(); ++i) {
    const char c = url[i];
    if (!isalnum(static_cast<unsigned char>(c)) && c != '.' && c != '-' && c != ':') return false;
  }
  for (unsigned i = 0; i < bypass.length(); ++i)
    if (bypass[i] <= ' ' || bypass[i] > '~') return false;
  for (unsigned i = 0; i < token.length(); ++i)
    if (token[i] <= ' ' || token[i] > '~') return false;
  Preferences p;
  if (!p.begin("delta-cloud", false)) return false;
  const bool ok = p.putString("url", url) > 0 && p.putString("bypass", bypass) > 0 &&
                  p.putString("token", token) > 0;
  p.end();
  if (!ok) return false;
  closeConnection();
  url_ = url;
  bypass_ = bypass;
  token_ = token;
  enabled_ = true;
  mode_ = "starting";
  error_ = "";
  atHome_ = false;
  homeSince_ = awaySince_ = lastScan_ = lastHeartbeat_ = retryAt_ = startRetryAt_ = 0;
  clearTransfer();
  return true;
}

String CloudSync::statusJson() const {
  char last[24];
  snprintf(last, sizeof(last), "%llu", (unsigned long long)lastSyncUnixMs_);
  String s = "{\"configured\":";
  s += enabled_ ? "true" : "false";
  s += ",\"mode\":\"";
  s += mode_;
  s += "\",\"error\":\"";
  s += error_;
  s += "\",\"site\":\"";
  s += url_;
  s += "\",\"pending\":";
  s += pending_;
  s += ",\"synced\":";
  s += synced_;
  s += ",\"rejected\":";
  s += rejected_;
  s += ",\"uploaded_this_boot\":";
  s += uploaded_;
  s += ",\"pruned_this_boot\":";
  s += pruned_;
  s += ",\"evicted_this_boot\":";
  s += evicted_;
  s += ",\"upload_id\":\"";
  s += id_;
  s += "\",\"offset\":";
  s += unsigned(offset_);
  s += ",\"bytes\":";
  s += unsigned(size_);
  s += ",\"clock_ready\":";
  s += unixMs() ? "true" : "false";
  s += ",\"last_sync_unix_ms\":";
  s += last;
  s += "}";
  return s;
}

void CloudSync::tick(bool connected, bool imuReady, bool active, float voltage) {
  if (!enabled_ || !logger_.ready()) return;
  const uint32_t now = millis();
  trackMotion(now, active);
  if (connected) home(now, imuReady, voltage);
  else away(now, imuReady);
  wasRecording_ = logger_.recording();
}

void CloudSync::trackMotion(uint32_t now, bool active) {
  if (!active) return;
  if (!activeSince_ || now - lastActiveMs_ > kMotionGapMs) activeSince_ = now ? now : 1;
  lastActiveMs_ = now ? now : 1;
}

bool CloudSync::startManual(uint64_t unixMs) {
  if (!enabled_) return logger_.start(unixMs, 'u');
  if (!makeRoomForStart(kPruneTargetBytes)) {
    error_ = "storage_full";
    return false;
  }
  return logger_.start(unixMs, 'u');
}
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

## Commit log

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2026-09-06 Add Stage 1B enclosure CAD and print exports
    [delta_collar_enclosure_v0_1_test_tray.stl, delta_collar_enclosure_v1.scad, delta_collar_enclosure_v1.stl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]
2026-09-09 Record Stage 1B measurements and v0.4 enclosure print kit
    [assembly.scad, delta_collar_enclosure_v0_3_fit_tray.scad, delta_collar_enclosure_v0_3_fit_tray.stl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]
2026-09-11 Add offline motion recorder and document assembled prototype bench results
    [partitions.csv]
2026-09-12 Log the redirect target when the site answers 3xx
    Browsers are now redirected from the configured host to another
    chatgpt.site subdomain; the device never follows redirects with
    credentials, so record the Location header to show which host to
    provision instead.
    Claude-Session: https://claude.ai/code/session_01UUgLSYVvzkAiUBxDyt7SU4
2026-09-12 Fix chunk reads across TLS and record the passing physical bench
    Keeping a file descriptor open across an HTTPS request made the next seek
    fail on the board, so each immutable chunk is reopened at its offset and a
    read failure is now logged. Provision the confirmed site host, add a
    PlatformIO fallback path and a macOS include path to the helper scripts.
    Physical result: a 70 s simulated outing recorded itself (e1c527b1, 1,071
    samples), closed 26 s after returning to home Wi-Fi, uploaded, and the site
    confirmed the same SHA-256; resumable upload and cloud-confirmed cleanup ran
    in the same session. Away sampling averaged 15.22 Hz, below the 18.97 Hz
    desktop baseline, and remains open.
    Co-Aut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
    [cloud_sync.cpp, cloud_sync.h]
2026-09-12 Stop walking the filesystem on every flush and reuse the TLS connection
    The measured sampling gaps (61 gaps over 70 s, 317 ms median, one per
    1.2 s) matched the per-second flush, not Wi-Fi: each flush asked LittleFS
    for exact free space, which walks every allocated block and slows down as
    the partition fills. Free space is now estimated between refreshes (30 s,
    or 5 s near the reserve) and a real write failure still stops recording.
    Uploads kept one TLS handshake per 16 KiB chunk, about 4.8 s per request.
    The socket is now reused across chunks and closed when leaving home, when
    idle and on failure, with one fresh-handshake retry if the site dropped it.
    Adds experiments/analyze_cloud_sync_r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
    [analyze_cloud_sync_run.py, cloud_sync.cpp, cloud_sync.h]
2026-09-12 Record the re-run: sampling back to 19.4 Hz, upload latency isolated
    Two physical runs after the flush and connection changes: 19.46 and
    19.43 Hz (was 15.22), 3.1% and 3.7% of time uncovered (was 28.5%), max
    interval 366 and 325 ms (was 760), both confirmed by the site with the
    same SHA-256. Between the runs the board finished the 2.30 MiB backlog by
    itself and pruned confirmed sessions, including the 1.75 MiB one.
    Reuse removes the handshake (first request 8.0-9.7 s, later ones ~4.2 s)
    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
2026-09-12 Keep the radio awake while syncing at home
    Measuring the same endpoint from the Mac on the same network gave 1,009 ms
    median on a new connection and 879 ms reused, against about 4.2 s per
    request on the board, so roughly 3.3 s per request was being spent on the
    board rather than at the site. At home the access point is stopped, so the
    station falls back to modem sleep and every round trip waits for the next
    wake-up. The radio now stays awake for the duration of a sync burst and
    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
2026-09-12 Record the site-side check with real uploaded data
    Signed in and verified the dashboard: 17 sessions / 2.50 MB, including
    sessions the board has already pruned locally, so the site holds the full
    history while the board keeps only recent ones. The largest session
    (73,119 samples, 1.75 MiB, ~71 min) renders in 1.53 s, exports 73,119 CSV
    rows in 1.16 s and downloads raw, so an hour-long walk needs no splitting.
    The page's uncovered time matches the board-side measurements.
    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
2026-09-12 Revert the radio change and log where each request's time goes
    Keeping the station awake made no difference on the board (4.43 s median
    per request against 4.24/4.39 before) and the first request after the
    change failed outright after 24 s, so the modem-sleep explanation is wrong
    and the change is removed.
    Instead every request now logs whether the socket was reused, the response
    code, elapsed milliseconds and what the site answered in its Connection
    header, which separates "a TLS handshake per request" from "the site is
    slow". Serial "T" (and cloud_sync_mac.sh cloudtest) times three read-only
    status probes so this can be measured in a minute instead of a full walk
    test.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
    [cloud_self_test.py, cloud_sync.cpp, cloud_sync.h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]
2026-09-12 Make selfTest public and check the public API in the host tests
    The build failed because selfTest() landed in the private section, which
    the host simulation could not catch: it compiles with -Dprivate=public.
    tests/cloud_sync_sim now also compiles api_check.cpp without that override,
    exercising exactly the calls main.cpp makes.
    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
    [cloud_sync.h]
2026-09-12 Hold one HTTPClient so the kept-alive socket survives
    The site answers Connection: keep-alive, yet every request still showed
    reused=0 and took about 4.2 s. Reading the core's HTTPClient for this
    version explains it: end() keeps the socket but leaves _client set, and
    ~HTTPClient() then calls _client->stop() unconditionally, so the
    per-request HTTPClient object closed the very connection it had kept. The
    client and the HTTPClient are now members configured once at begin().
    The probe script also waits for the board to boot before sending "T":
    opening the port resets it and the command was being lost.
    Claude-Session: https://claude.ai/code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
    [cloud_self_test.py, cloud_sync.cpp, cloud_sync.h]
2026-09-12 Confirm connection reuse on the board: 1.01 s per request
    Timing probe after holding one HTTPClient: a new connection costs
    3,959/4,303 ms and a reused one 1,012/1,031 ms, matching the 0.9 s the
    same endpoint answers a laptop in. The board's own overhead is gone; the
    ~3 s TLS handshake now happens once per sync burst instead of per request,
    which takes an hour-long recording from roughly 7.8 to 1.9 minutes.
    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
2026-09-12 Add offline gait and activity analysis for a session
    Computes a rest/walk/run time budget, a relative activity index and a
    stride-frequency track from one recording, so the split can be tuned
    without touching the firmware or the site: 4 s windows at 2 s hops, MAD
    and ENMO of the acceleration magnitude, gyro magnitude, and the dominant
    0.5-5 Hz component with its share of band power. At 20 Hz MAD separates
    movement far better than ENMO (bench: handling 100 mg vs 0.7 mg at rest,
    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
2026-09-12 Start a session from sustained movement, not only from leaving Wi-Fi
    The collar is worn only for outings, and home Wi-Fi can reach the places a
    walk goes, so movement itself now starts a session: active for about 30 s
    with no pause longer than 3 s, while still connected at home. Such a
    session ends after 5 minutes of stillness, which is the counterpart of the
    "back on home Wi-Fi" rule it cannot rely on. Leaving Wi-Fi still triggers
    recording as before, and an away session is never cut by stillness, so a
    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
2026-09-12 Calibrate rest/walk from a labelled indoor recording
    First session started by movement alone (header trigger 'm') while still on
    home Wi-Fi, ended by the stillness rule and uploaded without anyone
    touching the board: 6,724 samples at 19.53 Hz, 2.0 s uncovered.
    Labelled windows put rest at p90 4.2 mg against walk p10 102.9 mg, a
    factor of 25, and all 149 labelled windows agreed, so rest/walk is now set
    at 50 mg in both the offline script and the site. The run boundary is not
    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
    [gait_calibration_2026-09-11_labels.csv]
2026-09-12 Explain the frequency result: it is the carry, not the gait
    The user confirms normal walk first, fast walk second, board held in
    front of the chest without arm swing. Autocorrelation agrees with the FFT
    peak (2.86 vs 3.38 Hz for normal, 2.00 vs 1.88 Hz for fast), so the
    estimator is not picking the wrong harmonic: the arms act as a spring
    whose 2-5 Hz sway dominates while the torso bounce is small, and the step
    cadence only takes over once the walk is brisk (2.0 Hz = 120 steps/min).
    A harness mount is rigid to the trunk, so this should be checked again on
    the first worn recording.
    Claude-Session: https://claude.ai/code/session_01UUgLSYVv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
2026-09-12 Write up the evening: motion trigger, unattended loop and calibration
    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
2026-11-08 Rebuild the Delta model: continuous meshes, hair cards, Sheltie head
    Body (v2, from the reference photos): every part is a primitive union that
    is voxel-remeshed and smoothed into one surface; the blue-merle coat is
    painted per pixel from a 3D marking function via a world-position bake and
    covered with alpha-cut hair cards.
    Head (v3, after the owner's stylised sketch): wedge head with a short
    muzzle, wide white blaze to the crown, black eye patches breaking into
    speckles, black crown "wings" and a white mane ring made of sculpted
    feather-like clumps. Both eyes are plain dark eyes for now (textured iris,
    gloss, emissive catchlights).
    App: PetSceneView renders fur_* materials double-sided wi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
